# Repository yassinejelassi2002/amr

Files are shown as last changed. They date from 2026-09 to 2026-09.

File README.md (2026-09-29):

# AMR-X

AMR-X is an Autonomous Modular Robot - Extended project for a modular mobile robot platform and interchangeable functional modules.

To see the common commands for the website, MkDocs, dashboard, robot,
Gazebo worlds, navigation, and reports, run:

```bash
npm run commands
```

Filter the guide by category with commands such as `npm run commands -- robot`
or `npm run commands -- worlds`. `make help` shows the complete guide too.

This repository is structured for internship team work through GitHub issues, controlled CSV tables, LaTeX reports, and pull request review.

## Final Reports

- `reports/market_study/` - Final Market Study Report in LaTeX.
- `reports/v1_product_definition/` - Final V1 Product Definition Dossier in LaTeX.
- `reports/system_requirements_v1/` - Submitted SRD documents migrated as a standalone LaTeX report.

## Robotics Environment

The default robotics environment for this repository is:

- `Ubuntu 24.04`
- `ROS 2 Jazzy`
- `Gazebo Harmonic`

`Ubuntu 22.04 + ROS 2 Humble + Gazebo Fortress` is still allowed as a
compatibility path for teams that need to continue on the older setup.

Both teams must report any crash, launch failure, bridge mismatch, dependency
issue, or environment-specific problem immediately so the code and
documentation can be corrected quickly.

The default stack is the only acceptance target for new robotics work. The
older stack is a compatibility path, not a second implementation track.

Generated PDFs belong under `build/<report_name>/` and are not committed.

## Robotics Quick Start

The supported robotics stack is Ubuntu 24.04, ROS 2 Jazzy, and Gazebo
Harmonic. Build from the repository root:

```bash
source /opt/ros/jazzy/setup.bash
rosdep install --from-paths robotics --ignore-src -r -y
colcon build --symlink-install
source install/setup.bash
```

Launch the default warehouse simulation:

```bash
ros2 launch bringup simulation.launch.py
```

Launch the hospital instead:

```bash
ros2 launch bringup simulation.launch.py environment:=hospital
```

For SLAM, use separate sourced terminals:

```bash
# Terminal 1
ros2 launch bringup simulation.launch.py rviz:=false

# Terminal 2
ros2 launch navigation slam.launch.py

# Terminal 3
ros2 run teleop_twist_keyboard teleop_twist_keyboard
```

See the [complete robotics launch guide](robotics/LAUNCHING.md) for all worlds,
RViz, teleoperation, SLAM, map saving, live navigation, saved-map localization,
Fortress compatibility, topic checks, and troubleshooting.

## Source of Truth

- `config/project_specs.json` - Global project specifications.
- `data/bom/` - Controlled BOM source tables.
- `data/components/` - Component candidate source tables.
- `data/modules/` - Module decision and interface source tables.
- `data/requirements/` - Requirements matrix source tables.
- `reports/**/tables/generated/` - Generated LaTeX tables created from CSV and JSON sources.

Do not manually duplicate payload, dimensions, speed, endurance, or interface values in report prose. Use the global specs and generated tables.

## Module Scope

- `modules/base_platform/` - Base robot platform.
- `modules/arm_module/` - Robotic arm module.
- `modules/shelf_access_module/` - Shelf-access module.
- `modules/secure_compartment_module/` - Secure delivery compartment module.
- `modules/sensor_inspection_module/` - Sensor and inspection module.
- `modules/common_interface/` - Shared module mechanical, electrical, data, and safety interface.

Every major base component and every module must document a build, buy, modify, or custom-manufacture decision.

## Workflow

Issue -> Branch -> CSV/TEX edit -> Generate tables -> Pull request -> Review -> Merge

Run generators after changing `config/` or `data/`:

```bash
python3 tools/generate_specs.py
python3 tools/generate_latex_tables.py
```

Build reports into `build/<report_name>/`:

```bash
bash tools/build_reports.sh
```

Expected generated PDFs:

- `build/market_study/market_study.pdf`
- `build/v1_product_definition/v1_product_definition.pdf`
- `build/system_requirements_v1/system_requirements_v1.pdf`

## Local Website and Documentation

The documentation can run by itself. The Next.js landing page is optional.
The supported minimum versions are Python 3.10, Node.js 20.9, and npm 10.
Ubuntu is the primary local development environment.

### Documentation only (no website packages)

This path creates the shared root `.venv` and installs only the Python
documentation dependencies. The versions are pinned in
`requirements-docs.txt`, including the multilingual `mkdocs-static-i18n`
plugin:

```bash
git clone git@github.com:cybermech-hub/amr-x.git
cd amr-x
npm run setup:docs
npm run docs
```

Open <http://127.0.0.1:8001/>. You do not need to install anything under
`website/`. The setup script creates or reuses the single root `.venv`; do not
create another environment for documentation or the dashboard.

Always use `npm run docs` or `.venv/bin/python -m mkdocs`; a globally installed
`mkdocs` command does not use the repository's plugins. The supported command
checks the pinned toolchain and repairs missing documentation dependencies
before starting.

### Website and documentation together

```bash
git clone git@github.com:cybermech-hub/amr-x.git
cd amr-x
npm run setup
npm run dev
```

- Website: <http://localhost:3000/>
- Documentation: <http://localhost:3000/docs/>

French, German, and Arabic are available from the language selector:

| Language | Website | Documentation |
|---|---|---|
| English | <http://localhost:3000/> | <http://localhost:3000/docs/> |
| Français | <http://localhost:3000/fr/> | <http://localhost:3000/docs/fr/> |
| Deutsch | <http://localhost:3000/de/> | <http://localhost:3000/docs/de/> |
| العربية | <http://localhost:3000/ar/> | <http://localhost:3000/docs/ar/> |

English is the canonical documentation source. Localized Markdown files use
the `.fr.md`, `.de.md`, and `.ar.md` suffixes, with English fallback for pages
that have not yet been translated.

### How documentation translation works

Translation happens from Markdown source during the MkDocs build. It is not
performed dynamically in the browser, and the site does not call a runtime
translation service.

Current coverage:

- Documentation navigation and the homepage are translated into French,
  German, and Arabic.
- Technical pages currently use the English fallback until a translated
  Markdown file is added.
- Next.js landing-page translations are maintained separately in
  `website/lib/i18n.js`.

Translation files are stored beside the canonical English source:

```text
docs/robotics/simulation.md       # English
docs/robotics/simulation.fr.md    # French
docs/robotics/simulation.de.md    # German
docs/robotics/simulation.ar.md    # Arabic
```

They generate these routes:

```text
/docs/robotics/simulation/
/docs/fr/robotics/simulation/
/docs/de/robotics/simulation/
/docs/ar/robotics/simulation/
```

Do not translate commands, code, filenames, ROS identifiers, API paths, or
configuration keys. Preserve the technical structure and update translations
when the English source changes. See the
[documentation localization guide](docs/reference/localization.md) for the
complete workflow and current coverage.

`npm run setup` is safe to repeat. It prepares `.venv`, installs the MkDocs
dependencies, and installs the website packages. Press `Ctrl+C` once to stop
both development servers; run `npm run dev` to restart them. The optional
website alone can be prepared with `npm run setup:website` and started with
`npm run website`.

Edit the landing page under `website/app/`. Edit documentation Markdown under
`docs/`, and control its navigation in `mkdocs.yml`. MkDocs watches those files
and automatically refreshes open documentation pages. To add a page, create a
Markdown file under `docs/`, add it to `nav` in `mkdocs.yml`, and follow the
[documentation contributor guide](docs/contributing.md).

Before opening a pull request for the landing page or documentation, run
`npm run check`, or `npm run check:docs` when changing documentation only.
For dashboard changes, run `npm run check:dashboard`. Generated `site/`,
`website/.next/`, and dashboard `dist/` output must not be committed.

If a server reports that its port is busy, stop the process using port 3000,
3001, or 8001 and retry. In combined mode, the local gateway owns port 3000,
Next.js runs internally on port 3001, and MkDocs runs internally on port 8001.
If a command reports missing dependencies, run the matching setup command
again. If virtual-environment creation is unavailable on Ubuntu, install the
OS package that provides `python3-venv` for your Python version.

No public deployment, hosting provider, or GitHub Pages workflow is configured.

## Dashboard Development

The operator dashboard consists of a React/Vite frontend, a FastAPI backend,
and PostgreSQL 16 in Docker. It uses the same repository-root `.venv` as the
documentation toolchain; do not create a virtual environment under
`dashboard_app/`.

First-time setup:

```bash
npm run setup:dashboard
```

Start the complete dashboard:

```bash
npm run dashboard
```

This starts PostgreSQL, FastAPI, and Vite:

- Dashboard: <http://localhost:5173/>
- API documentation: <http://localhost:8000/docs>

Press `Ctrl+C` to stop the frontend and backend. PostgreSQL remains running so
its data is available next time. Stop it separately with
`npm run dashboard:db:stop`.

Individual services can also be run from the repository root:

```bash
npm run dashboard:db          # Start PostgreSQL
npm run dashboard:backend     # Start FastAPI on port 8000
npm run dashboard:frontend    # Start Vite on port 5173
npm run dashboard:db:status   # Show PostgreSQL status
npm run dashboard:db:logs     # Follow PostgreSQL logs
npm run dashboard:db:stop     # Stop PostgreSQL without deleting its data
npm run check:dashboard       # Check the backend and lint/build the frontend
```

See the [dashboard guide](dashboard_app/README.md), the
[backend guide](dashboard_app/backend/README.md), and the
[full ROS-to-dashboard setup](dashboard_app/SETUP.md) for more detail.

## Rules

- Start every task from a GitHub issue.
- Use `TBD` for undecided values.
- Do not invent market data, prices, suppliers, specifications, or citations.
- Do not commit private PDFs.
- Do not commit generated LaTeX build files or report PDFs.
- Keep source PDFs and references only when they are allowed to be shared.

See `CONTRIBUTING.md`, `.agents.md`, and the
[documentation contributor guide](docs/contributing.md).

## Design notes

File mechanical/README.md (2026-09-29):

# Mechanical

Mechanical design, CAD exports, and hardware specifications.

## Purpose

Define and document robot chassis, mounting interfaces, payload support, and mechanical architecture.

## CAD Tool

TBD - Tool selection pending.

## Git Storage Policy

Active CAD files (proprietary formats) are not stored in Git at the beginning. Store only:

- Exported STEP files
- Exported STL files
- PDF drawings and technical documentation
- Rendered images and concept visualizations
- Design concept notes

## Future Work

- Chassis design and optimization
- Modular add-on mounting standard
- Payload capacity and assumptions
- Serviceability and maintenance notes
- Material and manufacturing process specifications

## Subfolders

- `concepts/` - Design concepts and sketches
- `dimensions/` - Mechanical specifications and constraints
- `mounting_interface/` - Modular add-on interface design
- `exports/` - STEP, STL, drawings, and renders

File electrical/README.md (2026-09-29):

# Electrical

Electrical systems, power distribution, sensors, compute, and bill of materials.

## Purpose

Design and document electrical architecture for autonomous mobile robot platform.

## Electrical CAD Tool

TBD - Tool selection pending.

## Current Status

No component selection finalized yet. Design phase only.

## Architecture Areas

- **Power Distribution** - Voltage regulation, protection, distribution
- **Battery System** - Energy storage and management
- **Sensors** - Power requirements and interfaces
- **Compute** - Processing platform and controllers
- **Wiring** - Harness design and connections
- **Safety Systems** - Emergency stop, protection, monitoring
- **BOM** - Component tracking and specifications

## Security and Safety Notes

- Emergency stop must be designed with safety-critical approach
- Power protection circuits required for component safety
- No remote control without authentication (enforced at software level)
- All operator actions logged for audit trail

## Subfolders

- `power_system/` - Power distribution design
- `battery/` - Battery system specifications
- `sensors/` - Sensor selection and power requirements
- `compute/` - Compute platform details
- `wiring/` - Harness and connection design
- `safety/` - Safety systems and interlocks
- `bom/` - Bill of materials

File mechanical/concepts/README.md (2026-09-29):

# Concepts

Early design concepts and sketches for robot platform.

## Purpose

Document and iterate on mechanical design concepts before finalizing CAD models.

Store concept notes, sketches, and design rationale.

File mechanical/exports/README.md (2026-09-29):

# Exports

CAD file exports including STEP, STL, drawings, and renders.

## Purpose

Store exported CAD data suitable for manufacturing, simulation, and documentation.

## Subfolders

- `step/` - STEP format files for CAD interchange
- `stl/` - STL format files for 3D printing and simulation
- `drawings/` - PDF technical drawings
- `renders/` - Visualization renders and concept images

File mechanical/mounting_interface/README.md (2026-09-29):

# Mounting Interface

Modular add-on mounting interface and integration standard.

## Purpose

Define the mechanical, electrical, and software interface for modular add-ons and extensions.

Store mounting specifications, interface standards, and integration guidelines.

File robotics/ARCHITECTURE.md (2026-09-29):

# AMR-X Modular Architecture

Scaffold for expanding AMR-X from a mobile base into a modular mobile
manipulator. First module is a dual arm; the framework is general.

Status: skeleton that builds. Robot logic is TODO(team) stubs.

## Documentation map
- README.md       - base robot workspace (build/run the base)
- LAUNCHING.md    - run commands (sim, teleop, SLAM, Nav2)
- ARCHITECTURE.md - this file: the modular expansion (arm + modules)

## Packages

| Package | Build type | Role |
|---|---|---|
| amr_interfaces | ament_cmake | Shared msg/srv/action. BUILD FIRST. |
| arm_description | ament_cmake | Dual-arm module URDF/Xacro. |
| arm_control | ament_cmake | ros2_control controllers for arm joints. |
| arm_moveit_config | ament_cmake | MoveIt 2 planning (Setup Assistant output). |
| module_manager | ament_python | Runtime attach/detach + mode transitions. |
| task_coordinator | ament_python | Mission orchestration (mobile manipulation). |
| dashboard_bridge | ament_python | ROS 2 <-> dashboard telemetry/commands. |

Alongside existing base packages: robot_description, simulation, control,
navigation, bringup.

## Build

    cd ~/amr-x/robotics
    rosdep install --from-paths . --ignore-src -r -y
    colcon build --packages-select amr_interfaces
    source install/setup.bash
    colcon build
    source install/setup.bash

Human build order: amr_interfaces -> arm_description -> arm_control ->
arm_moveit_config -> module_manager / task_coordinator -> dashboard_bridge.

## Where to start (per package)

- amr_interfaces: refine and FREEZE the msg/srv/action definitions early.
- arm_description: fill config/arm_params.yaml, then single_arm.xacro (L+R),
  gripper.xacro, arm_gazebo.xacro. Goal: view the arm in RViz.
- arm_control: joint_trajectory_controller per arm + joint_state_broadcaster.
- arm_moveit_config: run MoveIt Setup Assistant on the arm URDF; commit output.
- module_manager: attach/detach (spawn controllers) + mode state machine.
- task_coordinator: pick-and-place behavior tree (navigate->grasp->place).
- dashboard_bridge: telemetry out / commands in, typed via amr_interfaces.

## Suggested ownership

- Interfaces + architecture: amr_interfaces, mount-frame convention.
- Description/sim: arm_description, simulation extensions.
- Control/motion: arm_control, arm_moveit_config.
- Coordination: module_manager, task_coordinator.
- Dashboard: dashboard_bridge, dashboard_app.

## Module mount interface (pending mechanical)

Guided by modules/common_interface/ (connector selection guides, not final spec).
- Base exposes one frame: module_mount_top; modules attach there.
- Per-module details in module_manager/config/modules.yaml.
- DUAL ARM: bolted-flange / kinematic mount (heavy, calibration-sensitive) ->
  NOT runtime hot-swappable; present at launch. Electrical: CAN + M8/M12.
- TODO(mechanical): confirm connector + which modules are hot-swappable.

## Simulator stack - MIXED (Fortress + Harmonic coexist)

Some members: ROS 2 Humble + Gazebo Fortress. Others: Jazzy + Harmonic. To cope:

| Thing | FORTRESS | Harmonic |
|---|---|---|
| DiffDrive plugin file | libignition-gazebo-diff-drive-system.so | gz-sim-diff-drive-system |
| Plugin namespace | ignition::gazebo::systems:: | gz::sim::systems:: |
| Sensor frame tag | <ignition_frame_id> | <gz_frame_id> |
| Bridge msg prefix | ignition.msgs.X | gz.msgs.X |
| Resource env var | IGN_GAZEBO_RESOURCE_PATH | GZ_SIM_RESOURCE_PATH |
| apt packages | ros-humble-* | ros-jazzy-* |

- Keep ALL simulator-specific strings in ONE file per package (*_gazebo.xacro,
  bridge YAML). State the target stack in each world/launch header.
- Prefer parameterizing plugin names via a xacro arg so one file targets either.
- Check a machine: echo $ROS_DISTRO (humble=Fortress, jazzy=Harmonic).

## Conventions

- Each package's params in a single config/*.yaml.
- Isolate simulator-specific tags in one xacro per package.
- build/ install/ log/ are git-ignored; never commit them.

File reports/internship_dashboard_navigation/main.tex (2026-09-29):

% Rapport de stage - Interface web de supervision et de commande AMR-X
% Compilation : latexmk -pdf -outdir=../../build/internship_dashboard_navigation main.tex
\documentclass[12pt,a4paper,oneside]{report}

\usepackage[utf8]{inputenc}
\usepackage[T1]{fontenc}
\usepackage{lmodern}
\usepackage[french]{babel}
\usepackage[a4paper,top=2.5cm,bottom=2.5cm,left=2.5cm,right=2.5cm,headheight=15pt]{geometry}
\usepackage{amsmath,amssymb}
\usepackage{graphicx}
\usepackage{booktabs,tabularx,multirow,longtable,array}
\usepackage[table]{xcolor}
\usepackage{caption,subcaption}
\usepackage{fancyhdr}
\usepackage{titlesec}
\usepackage{tocloft}
\usepackage{enumitem}
\usepackage{listings}
\usepackage{tikz}
\usetikzlibrary{arrows.meta,positioning,shapes.geometric,fit,calc,babel}
\usepackage{setspace}
\usepackage[hidelinks]{hyperref}

\setstretch{1.2}
\setlength{\parindent}{1.5em}
\setlength{\parskip}{0.4em}
\graphicspath{{figures/}}

% ---------------------------------------------------------------- numérotation
\renewcommand{\thechapter}{\Roman{chapter}}
\renewcommand{\thesection}{\arabic{section}}
\renewcommand{\thesubsection}{\arabic{section}.\arabic{subsection}}
\renewcommand{\thefigure}{\thechapter.\arabic{figure}}
\renewcommand{\thetable}{\thechapter.\arabic{table}}
\setcounter{secnumdepth}{3}
\setcounter{tocdepth}{2}

% ---------------------------------------------------------------- titres
\titleformat{\chapter}[display]
  {\normalfont\huge}{\chaptertitlename\ \thechapter}{1.2cm}{\Huge}
\titlespacing*{\chapter}{0pt}{2cm}{1.2cm}
\titleformat{\section}{\normalfont\Large\bfseries}{\thesection}{1em}{}
\titleformat{\subsection}{\normalfont\large\bfseries}{\thesubsection}{1em}{}
\captionsetup{labelsep=endash,font=small}
\captionsetup[figure]{name={\textsc{Figure}}}
\captionsetup[table]{name={\textsc{Tableau}}}

% ---------------------------------------------------------------- en-têtes
\pagestyle{fancy}
\fancyhf{}
\fancyhead[L]{\small\itshape\leftmark}
\fancyfoot[R]{\thepage}
\renewcommand{\headrulewidth}{0.4pt}
\renewcommand{\footrulewidth}{0.4pt}
\renewcommand{\chaptermark}[1]{\markboth{\chaptertitlename~\thechapter.\ #1}{}}
\fancypagestyle{plain}{\fancyhf{}\fancyfoot[C]{\thepage}%
  \renewcommand{\headrulewidth}{0pt}\renewcommand{\footrulewidth}{0pt}}

\renewcommand{\cfttoctitlefont}{\normalfont\Huge}
\renewcommand{\cftloftitlefont}{\normalfont\Huge}
\renewcommand{\cftlottitlefont}{\normalfont\Huge}
\renewcommand{\cftmarktoc}{\markboth{Table des matières}{}}
\renewcommand{\cftmarklof}{\markboth{Table des figures}{}}
\renewcommand{\cftmarklot}{\markboth{Liste des tableaux}{}}
\setlength{\emergencystretch}{3em}
\renewcommand{\topfraction}{0.9}
\renewcommand{\textfraction}{0.1}
\renewcommand{\floatpagefraction}{0.8}
\renewcommand{\cftdotsep}{1.5}
\renewcommand{\cftchapleader}{\hfill}

% ---------------------------------------------------------------- listings
\lstset{basicstyle=\ttfamily\small,columns=fullflexible,breaklines=true,
  frame=single,framerule=0.3pt,rulecolor=\color{gray!60},
  backgroundcolor=\color{gray!6},xleftmargin=0.5em,xrightmargin=0.5em,
  showstringspaces=false,upquote=true}

% ---------------------------------------------------------------- macros
% Valeur à compléter par l'auteur (organisme, encadrants, dates).
\newcommand{\acompleter}[1]{\textcolor{red!70!black}{[#1]}}
% Capture d'écran : insérée si le fichier existe dans figures/, sinon cadre réservé.
\newcommand{\capture}[3][0.9\linewidth]{%
  \IfFileExists{figures/#2}{}{%
    \fbox{\parbox[c][5.5cm][c]{#1}{\centering\small\itshape
      Capture à insérer : figures/#2\\[0.5em]\upshape #3}}}}
\newcommand{\code}[1]{\texttt{#1}}

% Style commun des schémas TikZ
\tikzset{
  bloc/.style={draw,rounded corners=3pt,thick,align=center,minimum height=1cm,
    inner sep=5pt,font=\small},
  web/.style={bloc,fill=blue!8},
  ros/.style={bloc,fill=orange!12},
  sim/.style={bloc,fill=green!10},
  neuf/.style={bloc,fill=red!8,draw=red!60!black,very thick},
  fl/.style={-{Stealth[length=2.5mm]},thick},
  lbl/.style={font=\scriptsize,align=center,fill=white,inner sep=1.5pt},
}

\begin{document}

\input{chapters/00_front}

\pagenumbering{roman}
\input{chapters/01_preliminaires}

\cleardoublepage
\pagenumbering{arabic}
\input{chapters/02_introduction}
\input{chapters/03_contexte}
\input{chapters/04_conception}
\input{chapters/05_realisation}
\input{chapters/06_validation}
\input{chapters/07_conclusion}

\end{document}

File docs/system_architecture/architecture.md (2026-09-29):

# AMR-X System Architecture v0.2

| Document control | Value |
|---|---|
| Owner | Technical Project Manager / System Architect |
| Status | Draft |
| Revision | `v0.2` |
| Controlled interface data | `data/system_architecture/interfaces.csv` |

!!! warning "Draft architecture"
    Proposed values and open conflicts are not approved requirements. Treat
    only entries explicitly marked **Confirmed** in the controlled interface
    data as confirmed decisions.

This document is the single reference for how the mechanical, electrical,
software, and module-interface decisions fit together. It should be updated
as teams confirm or change values. Detailed values live in
`data/system_architecture/interfaces.csv` — do not duplicate numbers here,
reference the table.

**Related implementation document:** `robotics/ARCHITECTURE.md`
covers the ROS 2 package-level implementation of the module software stack
in detail. This document stays at the system level and links out to it
rather than duplicating package contents — see Section 4.

## 1. Overview

AMR-X is a modular autonomous mobile robot. One base robot chassis accepts
interchangeable functional modules (inspection, secure cargo, handling,
robotic arm) through a shared docking interface. The base handles movement,
navigation, and power; the module handles the task-specific function. The
dual-arm module has been confirmed as the first module to be built (V1).

### Responsibility boundaries

| System element | Primary responsibility |
|---|---|
| Mobile base | Movement, navigation, base power, and module support |
| Functional module | Task-specific mechanical and software capability |
| Shared docking interface | Mechanical alignment and retention, power, data, and safety boundaries |
| Module manager | Module identification and software lifecycle coordination |

## 2. Mechanical Architecture

- Overall footprint: 800 mm x 600 mm x 420 mm (confirmed by Mechanical team)
- Drive: differential drive
- Wheels: 4 caster wheels (changed from 2 for stability and load
  distribution, relevant now that a heavier dual-arm module is planned)
- Module mounting zone: 500 mm x 400 mm, centered over the wheelbase
- A real CAD-exported URDF has been produced and integrated into
  simulation (see Section 4). Driving behavior and LiDAR output from the
  real model are still being validated.
- The dual-arm module is expected to require a center-of-gravity
  compensation of roughly 30-50 mm toward the rear (proposed, not yet
  validated in CAD)

Open item: internal component layout (battery, controller, wiring) is
still waiting on the Electrical team's final part list.

<div class="visual-grid">
  <figure>
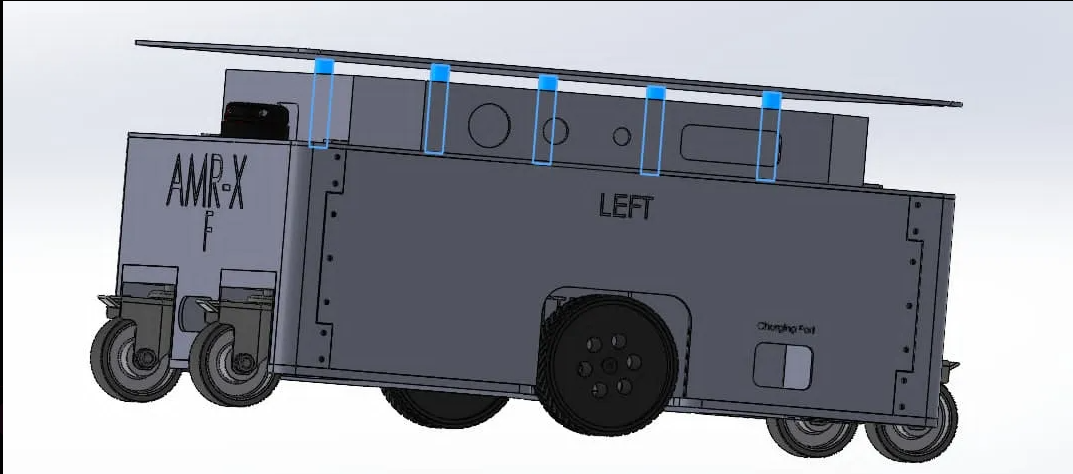
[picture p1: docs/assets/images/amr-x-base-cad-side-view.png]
Current AMR-X mobile base CAD side-view capture
    
    <figcaption><strong>Current base CAD capture.</strong><span>Progress image only; controlled dimensions remain in project data.</span></figcaption>
  </figure>
  <figure>
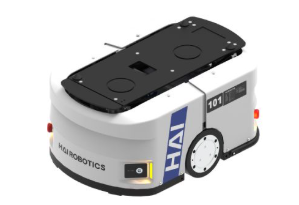
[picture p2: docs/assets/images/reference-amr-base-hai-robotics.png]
Third-party AMR base used as a form-factor reference
    
    <figcaption><strong>Base form-factor reference.</strong><span>External reference placeholder, not AMR-X.</span></figcaption>
  </figure>
  <figure>
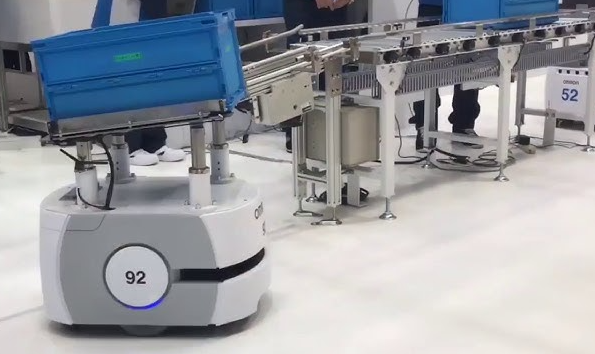
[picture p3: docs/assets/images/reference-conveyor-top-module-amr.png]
Third-party AMR with a conveyor top module
    
    <figcaption><strong>Top-module reference.</strong><span>External material-transfer example, not AMR-X.</span></figcaption>
  </figure>
</div>

## 3. Electronics Architecture

- Battery: TBD, active research in progress
- Main computer / controller: TBD
- Motor drivers: TBD

Open item: none of these are selected yet. This remains the biggest
blocker for Mechanical's internal layout.

## 4. Software Architecture

- ROS 2 stack locked: **Ubuntu 24.04 + ROS 2 Jazzy + Gazebo Harmonic** as
  the default, with **Ubuntu 22.04 + ROS 2 Humble + Gazebo Fortress** kept
  as a supported compatibility path
- Full simulation loop is working end-to-end: the robot drives in a
  warehouse world with working teleoperation and LiDAR/IMU/odometry
  publishing correctly
- The real CAD-exported URDF is integrated and spawns correctly in Gazebo,
  replacing the earlier placeholder model. Still to confirm: driving
  behavior and `/scan` output from the real sensor configuration
- **Module software scaffold merged into main (PR #8):** 7 ROS 2 packages
  — `amr_interfaces`, `arm_description`, `arm_control`, `arm_moveit_config`,
  `module_manager`, `task_coordinator`, `dashboard_bridge`. This is an
  empty-but-buildable skeleton with real logic left as TODOs per package
  owner. Full detail in `robotics/ARCHITECTURE.md`. **Merged on 8 Jul
  without the frame-naming conflict below being resolved first.**
- Arm control will use **MoveIt2**, not Nav2, since the dual-arm module's
  job is manipulation rather than mobile navigation
- Dashboard communicates with ROS 2 over `rosbridge_server` and
  `roslibjs` via WebSocket; confirmed working for `/cmd_vel`, with
  `/odom` and `/imu` subscriptions planned next

<div class="visual-grid visual-grid--two">
  <figure>
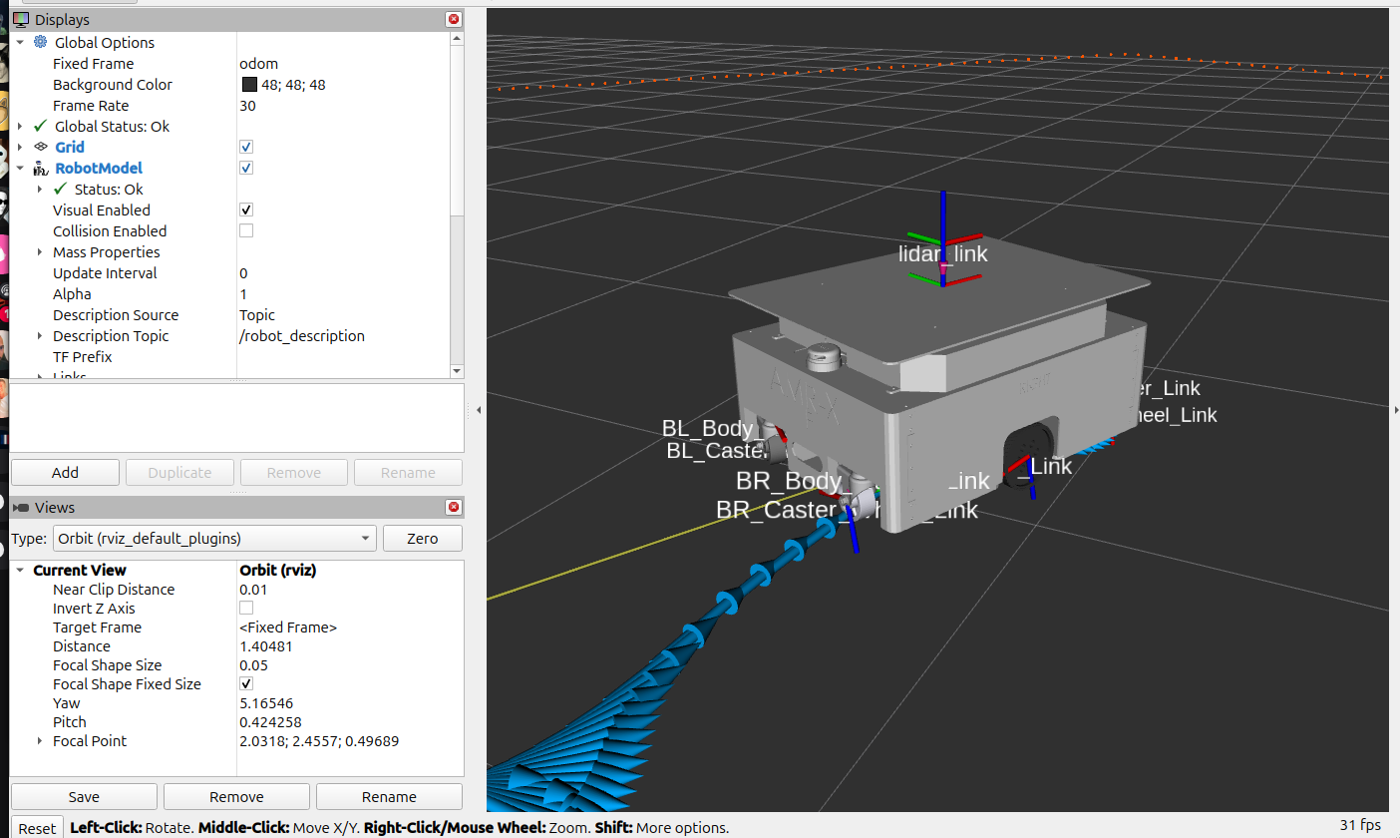
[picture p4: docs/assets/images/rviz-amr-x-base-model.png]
AMR-X base model and frames in RViz
    
    <figcaption><strong>AMR-X base in RViz.</strong><span>Robot-model integration capture.</span></figcaption>
  </figure>
  <figure>
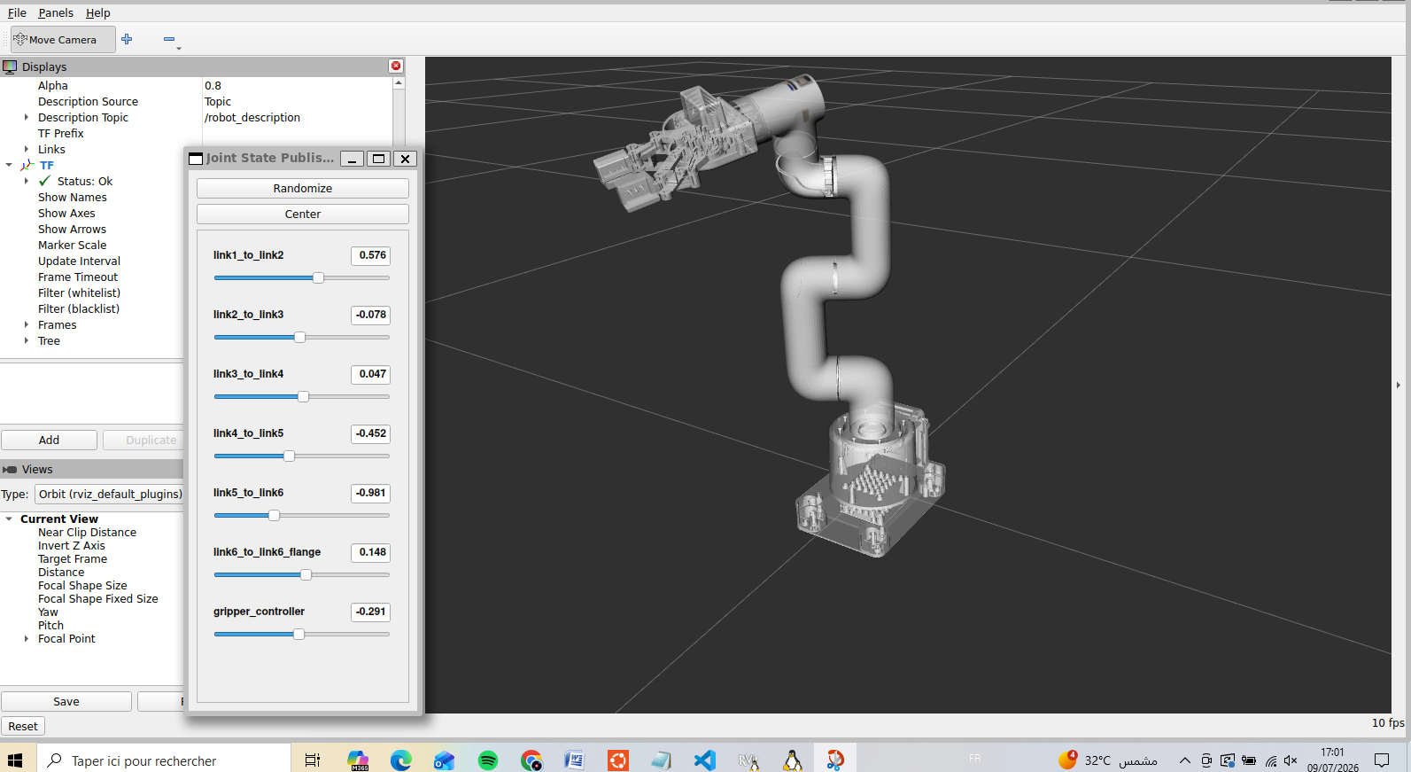
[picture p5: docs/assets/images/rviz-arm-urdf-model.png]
Arm URDF and joint states in RViz
    
    <figcaption><strong>Arm URDF in RViz.</strong><span>Manipulation-model integration capture.</span></figcaption>
  </figure>
  <figure>
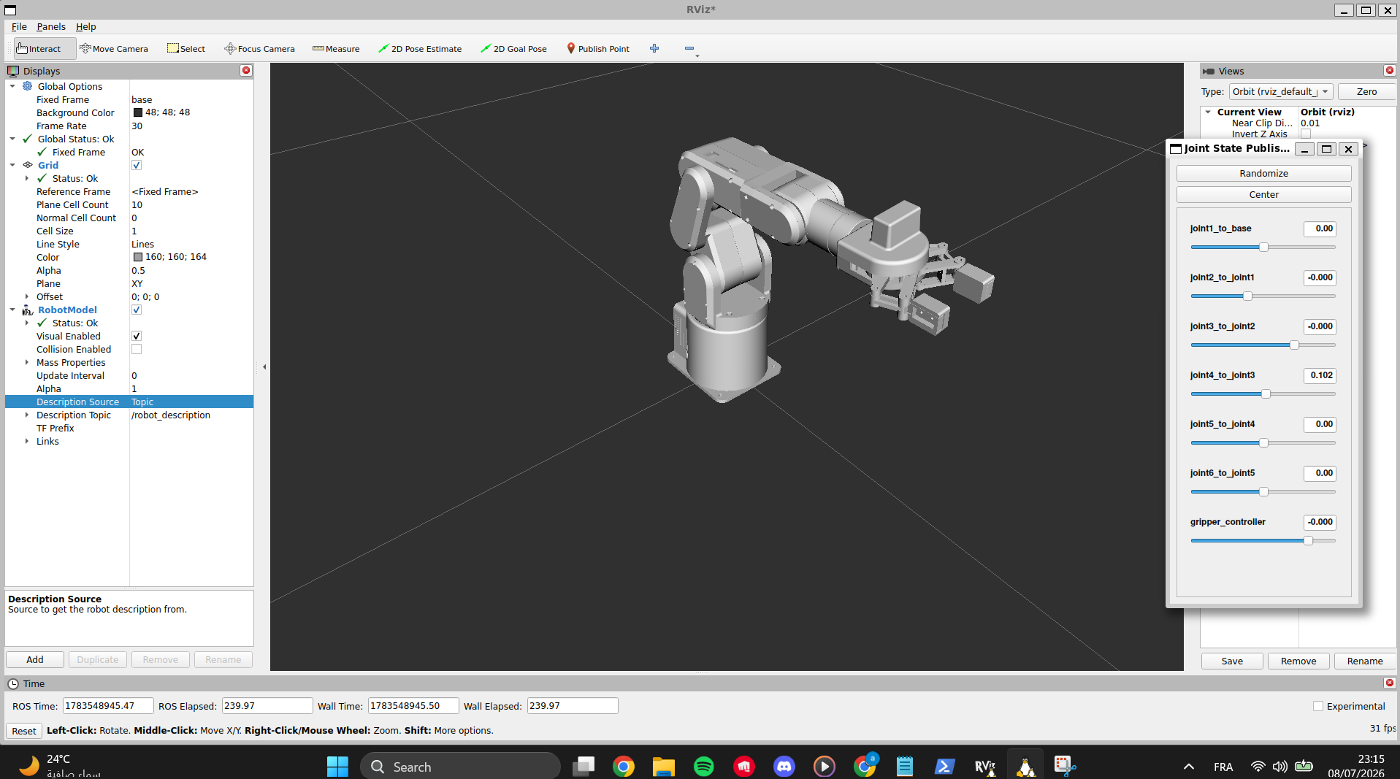
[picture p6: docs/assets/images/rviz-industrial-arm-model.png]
Alternative industrial arm model displayed in RViz
    
    <figcaption><strong>Alternative arm in RViz.</strong><span>Model visualization capture.</span></figcaption>
  </figure>
  <figure>
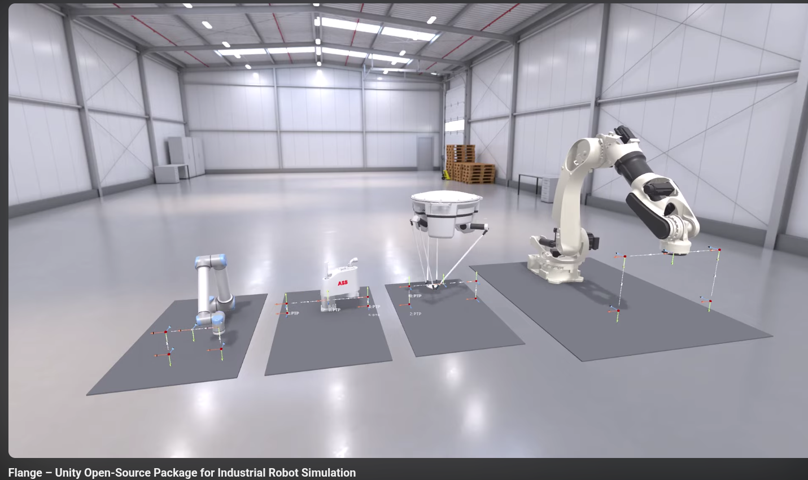
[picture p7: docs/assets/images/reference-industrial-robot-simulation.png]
Industrial robot simulation environment reference
    
    <figcaption><strong>Simulation presentation reference.</strong><span>External reference placeholder, not the AMR-X simulator.</span></figcaption>
  </figure>
</div>

## 5. Module Interface

- Connector: HARTING Han-Modular, carrying 24V power, CAN bus, and
  Ethernet
- Docking alignment: 12 mm diameter guide pins on a 450 x 350 mm pattern
- Docking locks: quarter-turn M8 locks, rated to 375 kg
- Docking detection: 2 inductive sensors, published to ROS topics
  `/module_docked` and `/module_id`
- Clearance zones defined so future modules cannot block the front LiDAR,
  emergency stop, or operator panel
- **Open conflict — module mount frame naming:** the mechanical/URDF side
  refers to the mount point as `module_interface_link`, while the new ROS
  package scaffold from PR #8 defines it as `module_mount_top`. These need
  to be reconciled to a single canonical name before more packages are
  built assuming either one. See Section 9.

## 6. Sensor Layout

- Proposed: dual LiDAR (front + rear) for 360-degree coverage and
  redundancy, proposed by Mechanical
- The currently integrated test URDF places a single LiDAR link at the
  front-top-centre position, matching CAD — this does not yet confirm
  whether the dual-LiDAR plan is still active or has been narrowed to one
- **Still not confirmed by Navigation/ROS team** — flagged as an open
  conflict, see Section 9

## 7. Navigation

- Nav2 configured, but currently using a placeholder footprint
- SLAM and AMCL localization tested successfully against the placeholder
  robot model; an EKF sensor-fusion config is currently being drafted
- Now that a real URDF is integrated, the footprint may be finalizable
  soon once the caster layout is locked

<div class="visual-grid">
  <figure>
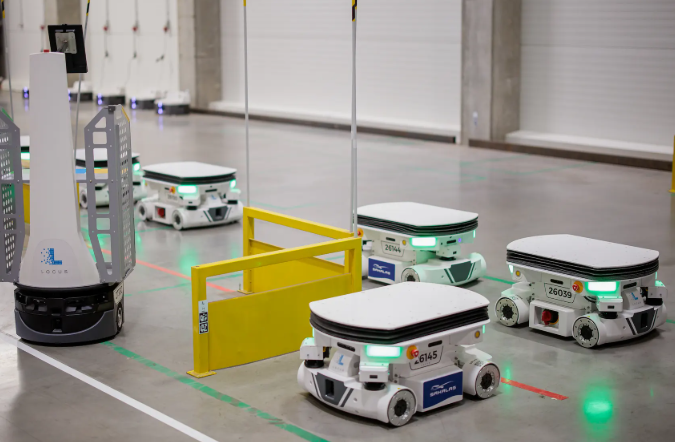
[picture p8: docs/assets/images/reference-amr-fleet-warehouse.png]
Fleet of third-party AMRs operating in a warehouse
    
    <figcaption><strong>Fleet-operation reference.</strong><span>External multi-robot environment placeholder.</span></figcaption>
  </figure>
  <figure>
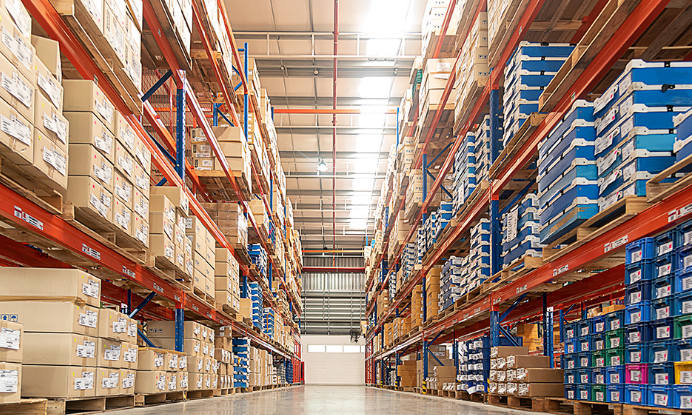
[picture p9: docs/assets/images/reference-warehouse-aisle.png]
Warehouse aisle used as an environment reference
    
    <figcaption><strong>Warehouse environment.</strong><span>Reference placeholder for navigation context.</span></figcaption>
  </figure>
  <figure>
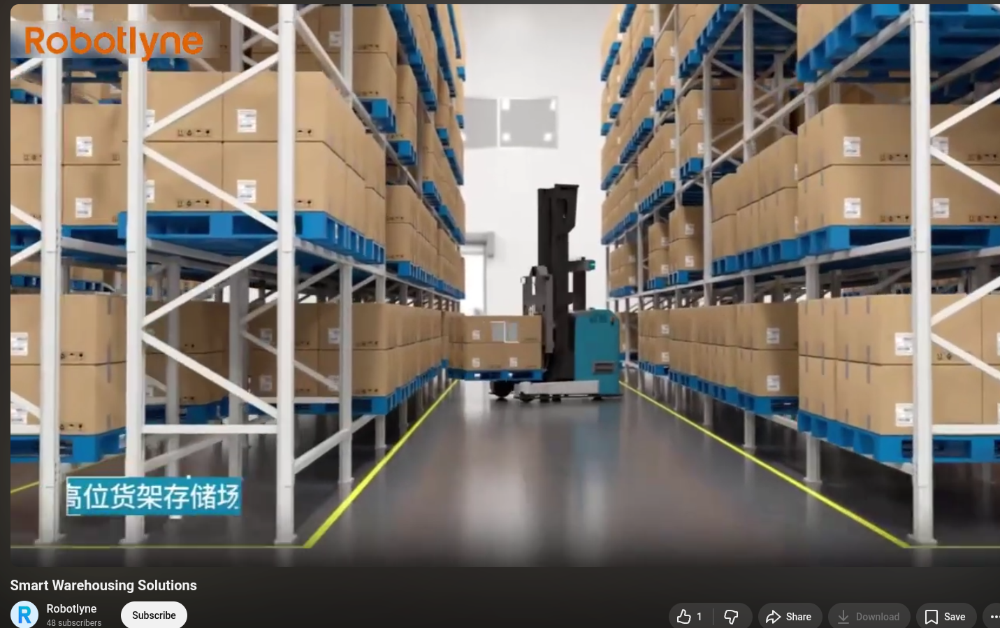
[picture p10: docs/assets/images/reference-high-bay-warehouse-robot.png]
Third-party robot operating in a high-bay warehouse
    
    <figcaption><strong>High-bay operation reference.</strong><span>External storage use-case placeholder.</span></figcaption>
  </figure>
</div>

## 8. Power Distribution

TBD — depends entirely on Electrical team's battery and controller
selection, which is under active research. No layout can be finalized
until this is resolved.

## 9. Known Conflicts / Open Questions

!!! danger "Integration blockers"
    This section identifies unresolved decisions that can invalidate work in
    more than one subsystem. Keep it synchronized with the controlled
    interface data.

1. **[NEW, urgent — now live in main]** Module mount frame naming
   conflict: `module_interface_link` (mechanical/URDF) vs
   `module_mount_top` (merged via PR #8). This is no longer a
   before-it-happens risk — PR #8 was merged into `main` on 8 Jul without
   this being reconciled, so the mismatch is now sitting in the codebase.
   Needs an issue opened and a decision between the Module team and
   ROS/Sim team on which name is canonical, then a follow-up fix wherever
   the losing name was used.
2. Mechanical proposes 2 LiDARs; the currently integrated URDF only shows
   one LiDAR link. Needs explicit confirmation from Navigation/ROS on
   whether the dual-LiDAR plan is still active.
3. Navigation's footprint is still a placeholder; likely close to
   resolution now that the real URDF is integrated, pending final caster
   layout confirmation.
4. Electrical has not selected a battery or controller yet, which blocks
   Mechanical's internal layout.
5. **[NEW]** Two parallel architecture documents now exist — this
   document (system-level) and `robotics/ARCHITECTURE.md` (ROS
   package-level, from PR #8). Agreed approach: this document stays at
   the system/interface level and links to `ARCHITECTURE.md` for
   implementation detail, rather than the two documents duplicating each
   other. Confirm this approach across the affected workstreams.

## 10. Future Modules

**Confirmed V1 module: dual-arm robotic arm module.** Mechanical is
researching hardware options (GrabCAD models); software has scaffolded
the arm packages (`arm_description`, `arm_control`, `arm_moveit_config`).

Candidate module research (from the module research source, see
`Modules.pdf`):

- **Robotic arm:** Interbotix PincherX/WidowX (ROS-ready "arm + mobile
  base" kits, ~$2,000-6,500), Elephant Robotics myCobot 280/320
  (lightweight, ~$1,000-2,000, lower payload), uFactory xArm/Lite
  (higher payload up to 5kg, ~$3,300-10,000)
- **Shelf access:** Nord Modules Quick Mover/Pallet Lift (4-screw
  mounting, up to 1500kg), ROEQ Top Modules (MiR-compatible, built-in
  alignment/load sensors), Ocado Chuck (design reference only, not
  purchasable)
- **Inspection:** Clearpath Husky Observer (turnkey, ROS API, 10kg
  payload budget), or individually-assembled components (e-con Systems
  cameras, Orbbec depth sensors, thermal imaging modules) — likely the
  more realistic budget option

Not yet scoped: shelf-access and inspection modules remain future work
beyond the dual-arm V1.

!!! info "Concept imagery"
    The images below are communication placeholders, not approved production
    geometry. Third-party references do not represent AMR-X work and require
    provenance and licensing review before external use.

### Dual-arm and mobile-manipulation direction

<div class="visual-grid">
  <figure>
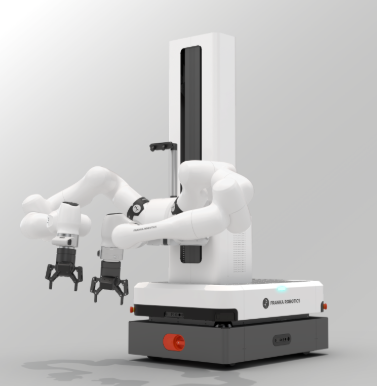
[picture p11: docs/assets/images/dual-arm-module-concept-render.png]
Dual-arm module concept placeholder
    
    <figcaption><strong>Dual-arm module direction.</strong><span>V1 concept placeholder.</span></figcaption>
  </figure>
  <figure>
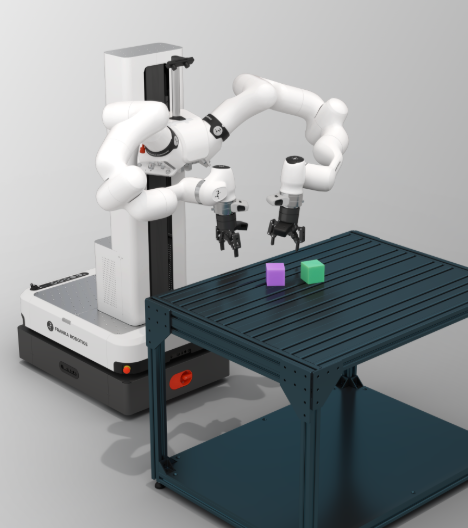
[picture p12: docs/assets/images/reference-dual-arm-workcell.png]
Third-party dual-arm workcell reference
    
    <figcaption><strong>Dual-arm workcell reference.</strong><span>External workspace placeholder, not AMR-X.</span></figcaption>
  </figure>
  <figure>
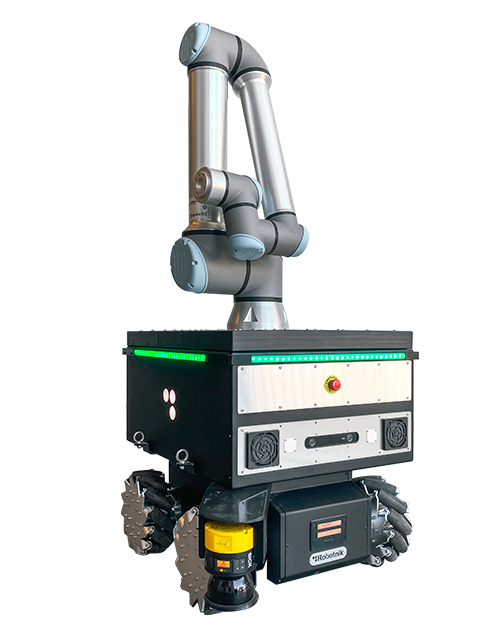
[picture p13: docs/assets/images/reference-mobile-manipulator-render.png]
Third-party mobile manipulator render
    
    <figcaption><strong>Manipulator packaging reference.</strong><span>External reference placeholder, not AMR-X.</span></figcaption>
  </figure>
  <figure>
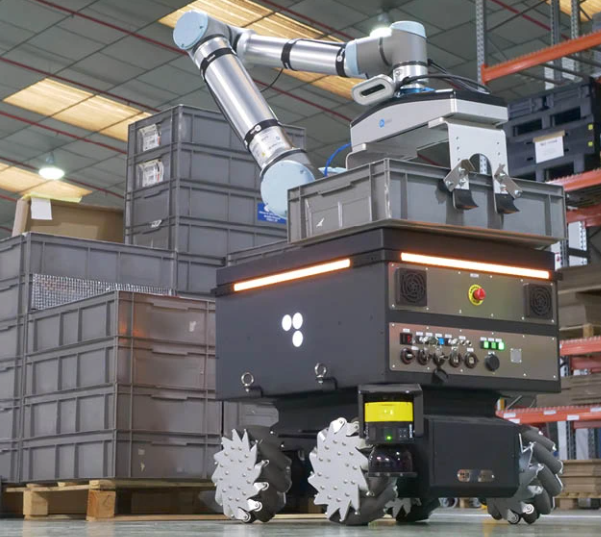
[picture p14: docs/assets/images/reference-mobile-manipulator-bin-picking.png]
Third-party mobile manipulator handling bins
    
    <figcaption><strong>Bin-handling reference.</strong><span>External use-case placeholder, not AMR-X.</span></figcaption>
  </figure>
  <figure>
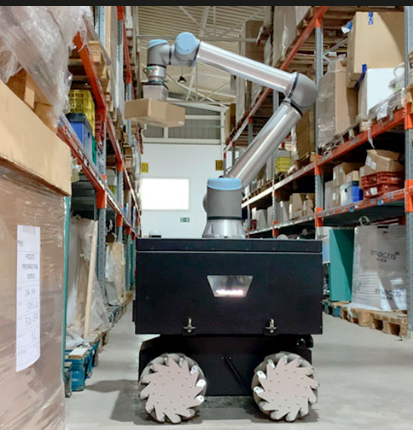
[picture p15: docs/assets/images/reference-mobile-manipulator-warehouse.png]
Third-party mobile manipulator in a warehouse aisle
    
    <figcaption><strong>Aisle-manipulation reference.</strong><span>External use-case placeholder, not AMR-X.</span></figcaption>
  </figure>
</div>

### Secure-compartment direction

<div class="visual-grid visual-grid--two">
  <figure>
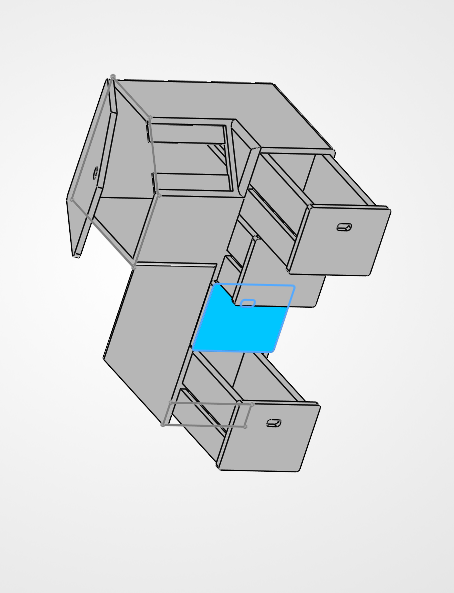
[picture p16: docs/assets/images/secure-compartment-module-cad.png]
Secure compartment module concept placeholder
    
    <figcaption><strong>Secure-compartment CAD.</strong><span>Future-module concept placeholder.</span></figcaption>
  </figure>
  <figure>
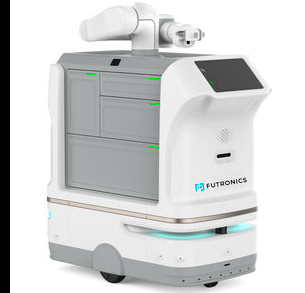
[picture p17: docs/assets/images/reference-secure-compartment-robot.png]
Third-party secure compartment robot reference
    
    <figcaption><strong>Compartment robot reference.</strong><span>External reference placeholder, not AMR-X.</span></figcaption>
  </figure>
</div>

### Shelf-access direction

<div class="visual-grid">
  <figure>
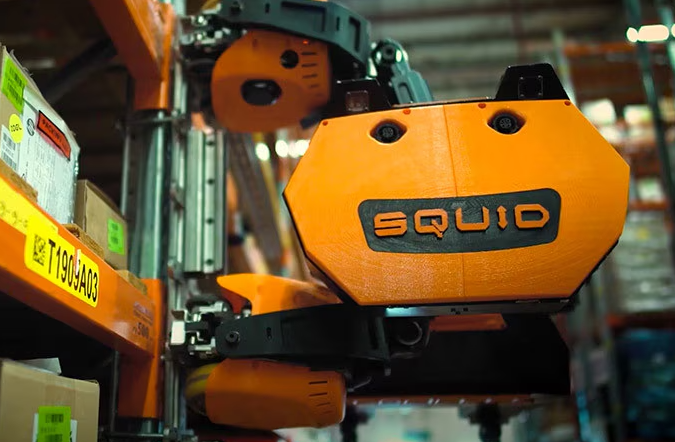
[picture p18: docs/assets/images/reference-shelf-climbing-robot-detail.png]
Detail of a third-party shelf-climbing robot
    
    <figcaption><strong>Rack-interface detail.</strong><span>External reference placeholder, not AMR-X.</span></figcaption>
  </figure>
  <figure>
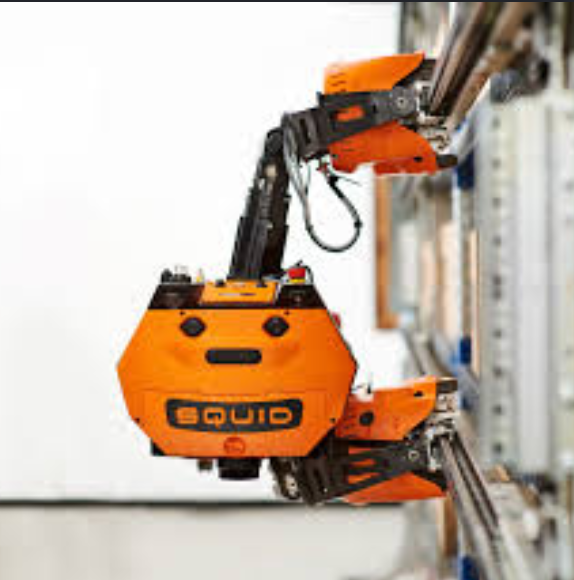
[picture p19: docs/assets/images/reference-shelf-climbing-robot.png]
Third-party shelf-climbing warehouse robot
    
    <figcaption><strong>Vertical-access reference.</strong><span>External reference placeholder, not AMR-X.</span></figcaption>
  </figure>
  <figure>
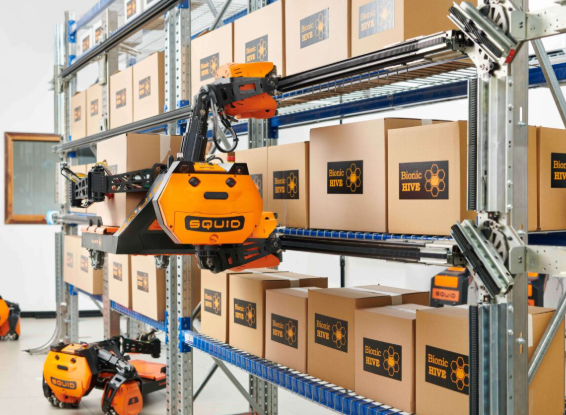
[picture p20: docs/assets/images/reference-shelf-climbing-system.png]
Third-party shelf-climbing robots operating on racks
    
    <figcaption><strong>Rack-automation system.</strong><span>External reference placeholder, not AMR-X.</span></figcaption>
  </figure>
</div>

---
*Change log*
- v0.1 — initial draft
- v0.2 — added dual-arm module confirmation, real URDF integration status,
  locked ROS stack decision, PR #8 module scaffold cross-reference, module
  mount frame naming conflict, precise docking hardware specs from
  module research source, dashboard communication method

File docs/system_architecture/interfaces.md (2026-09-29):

# System Interface Table

This register presents confirmed and open technical decisions across teams.
The authoritative source is `data/system_architecture/interfaces.csv` in the
repository.

!!! warning "Do not edit values in two places"
    Update the CSV source first, then synchronize this rendered table. A value
    marked **Proposed**, **Blocked**, **In Progress**, or **Conflict** is not a
    confirmed requirement.

Status meanings:

| Status | Interpretation |
|---|---|
| Confirmed | Accepted cross-team decision |
| Proposed | Candidate value requiring validation or approval |
| In Progress | Implementation or verification is incomplete |
| Blocked | A prerequisite decision or input is missing |
| Conflict | Current sources or implementations disagree |

| Category | Parameter | Value | Source Team | Status | Notes |
|---|---|---|---|---|---|
| Dimensions | Length | 800 mm | Mechanical | Confirmed |  |
| Dimensions | Width | 600 mm | Mechanical | Confirmed |  |
| Dimensions | Height | 420 mm | Mechanical | Confirmed |  |
| Mobility | Drive Type | Differential | Mechanical | Confirmed |  |
| Mobility | Caster Wheels | 4 | Mechanical | Confirmed | Changed from 2 to 4 for stability and load distribution |
| Sensors | LiDAR Count | 2 (front + rear) proposed; current integrated URDF shows a single LiDAR link | Mechanical | Needs ROS validation | Current URDF integration places one LiDAR link at front-top-centre; dual-LiDAR still not explicitly confirmed by Navigation/ROS |
| Sensors | LiDAR Coverage | 360 degrees combined if dual-LiDAR is confirmed | Mechanical | Proposed |  |
| Interface | Module Zone | 500 x 400 mm | Module Team | Confirmed |  |
| Interface | Connector Type | HARTING Han-Modular (24V power + CAN bus + Ethernet) | Module Team | Confirmed |  |
| Interface | Alignment Pins | 12 mm diameter pins on a 450 x 350 mm pattern | Module Team | Confirmed | Precise dimensions added from the module research source |
| Interface | Docking Locks | Quarter-turn M8 locks rated to 375 kg | Module Team | Confirmed | Load rating added from the module research source |
| Interface | Docking Detection | 2 inductive sensors | Module Team | Confirmed | Publishes to ROS topics `/module_docked` and `/module_id` |
| Interface | Clearance Zones | Defined around front LiDAR emergency stop and operator panel | Module Team | Confirmed | Modules cannot block these zones |
| Interface | Module Mount Frame Name | CONFLICT (now live in main): `module_interface_link` (mechanical/URDF side) vs `module_mount_top` (merged PR #8 ROS package scaffold) | Module Team + ROS/Sim Team | Conflict - needs resolution | PR #8 merged into main on 8 Jul without this being reconciled; needs an issue opened and a decision before more code/CAD builds on either name |
| Software | ROS Stack | ROS 2 Jazzy on Ubuntu 24.04 + Gazebo Harmonic (default); ROS 2 Humble + Gazebo Fortress kept as compatibility path | ROS/Sim Team | Confirmed | Locked by the approved stack update |
| Software | URDF Status | Real CAD-exported URDF integrated and spawns correctly in Gazebo | ROS/Sim + Mechanical | In Progress | Driving and `/scan` output not yet confirmed; final sensor placement pending |
| Software | Full Simulation Loop | Robot drives in warehouse world with working teleop and LiDAR/IMU/odometry publishing | ROS/Sim Team | Confirmed |  |
| Software | Module Software Scaffold | 7 ROS 2 packages: `amr_interfaces`, `arm_description`, `arm_control`, `arm_moveit_config`, `module_manager`, `task_coordinator`, `dashboard_bridge` | ROS/Sim Team | Merged into main (PR #8) | Empty-but-buildable skeleton with TODOs; see `robotics/ARCHITECTURE.md`; needs sync with this document; see conflict row above |
| Module | First Module Choice | Dual-arm robotic arm module | Module Team + ROS/Sim Team | Confirmed | Chosen collaboratively; mechanical researching arm hardware; software scaffolding arm packages |
| Module | Arm Control Framework | MoveIt2 (not Nav2) | ROS/Sim Team | Confirmed | Focus is manipulation; not mobile navigation |
| Module | CG Compensation for Dual-Arm | Approximately 30-50 mm rearward shift anticipated | Mechanical | Proposed | From the module research source; not yet validated in CAD |
| Navigation | Footprint | TBD | Navigation Team | Blocked | Real URDF now integrated; so this may resolve soon once caster layout is finalized |
| Navigation | Nav2 Configuration | Configured with placeholder footprint | Navigation Team | In Progress |  |
| Navigation | Localization | SLAM + AMCL configured; EKF config in progress | Navigation Team | Confirmed | EKF configuration is in progress |
| Power | Battery | TBD | Electrical Team | Blocked | Active research in progress |
| Power | Main Computer / Controller | TBD | Electrical Team | Blocked |  |
| Electronics | Motor Drivers | TBD | Electrical Team | Blocked |  |
| Dashboard | Communication Method | `rosbridge_server` + `roslibjs` over WebSocket bridging ROS 2 topics to the browser frontend | Dashboard Team | Confirmed - tested working | Publishes `/cmd_vel` while a directional button is held; next is subscribing to `/odom` and `/imu` |

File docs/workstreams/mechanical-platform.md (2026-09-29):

# Mechanical Platform

## Responsibility

The mechanical platform workstream defines the reusable mobile base: chassis,
mobility, internal packaging, structural support, service access, and the
physical boundary presented to functional modules.

<figure class="technical-figure">
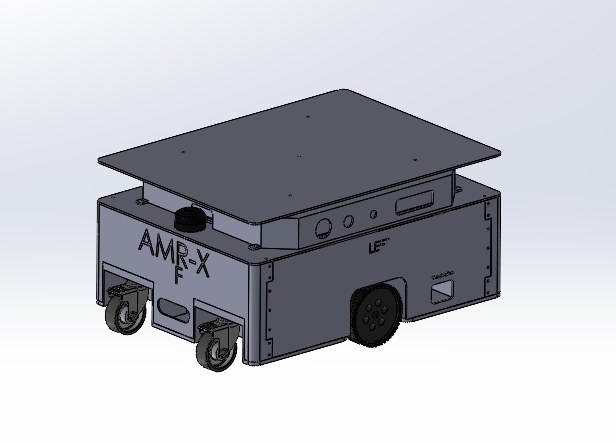
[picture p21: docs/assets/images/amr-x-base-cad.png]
AMR-X mobile base three-quarter CAD concept
  
  <figcaption><strong>Base-platform CAD concept.</strong> Use this image to communicate layout progress, not released manufacturing geometry.</figcaption>
</figure>

## Engineering activities

- Compare mobility and chassis concepts against controlled requirements.
- Maintain mass, payload, structural-load, stability, and center-of-gravity
  reasoning.
- Package the battery, compute, drivers, wiring, sensors, brakes, and service
  access without blocking safety devices or module clearance.
- Define mounting, alignment, retention, and docking geometry with the common
  interface workstream.
- Maintain CAD assemblies and approved exports with traceable revisions.

## Required interfaces

| Interface | Mechanical concern |
|---|---|
| Electrical and embedded | Component envelopes, cooling, wiring paths, connectors, access, and isolation |
| Navigation and perception | Sensor position, field of view, occlusion, footprint, and ground clearance |
| Modules | Mounting zone, loads, center of gravity, alignment, locking, and clearance |
| ROS 2 and simulation | Link geometry, joint definitions, frame locations, collision geometry, and inertial data |
| Safety | Emergency-stop access, braking provisions, guarding, maintenance, and safe handling |

## Expected outputs

- Selected base concept and conceptual CAD assembly.
- Mobility, load, stability, and packaging rationale.
- Internal layout and maintenance-access plan.
- Module-interface geometry and clearance definition.
- Simulation-ready geometry and verified frame reference points.
- Decision, risk, and validation records for unresolved mechanical choices.

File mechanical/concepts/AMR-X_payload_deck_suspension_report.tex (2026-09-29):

\documentclass[11pt,a4paper]{article}

% ---------- packages ----------
\usepackage[T1]{fontenc}
\usepackage[utf8]{inputenc}
\usepackage{amsmath}
\usepackage[margin=2.3cm]{geometry}
\usepackage[table]{xcolor}
\usepackage{booktabs}
\usepackage{array}
\usepackage{tabularx}
\usepackage{enumitem}
\usepackage{titlesec}
\usepackage{fancyhdr}
\usepackage{graphicx}
\usepackage[hidelinks]{hyperref}

% ---------- colours ----------
\definecolor{navy}{HTML}{000000}
\definecolor{accent}{HTML}{000000}
\definecolor{lightblue}{HTML}{F2F2F2}
\definecolor{lightgreen}{HTML}{E8E8E8}
\definecolor{amber}{HTML}{ECECEC}
\definecolor{greyln}{HTML}{808080}

% ---------- section styling ----------
\titleformat{\section}{\Large\bfseries\color{navy}}{\thesection.}{0.6em}{}[{\color{accent}\titlerule[1pt]}]
\titleformat{\subsection}{\large\bfseries\color{black!80}}{\thesubsection}{0.6em}{}
\titlespacing*{\section}{0pt}{14pt}{6pt}

% ---------- header / footer ----------
\pagestyle{fancy}\fancyhf{}
\renewcommand{\headrulewidth}{0.3pt}
\lhead{\small\color{navy}AMR-X Prototype V1}
\rhead{\small\color{navy}Payload-Deck Suspension Study}
\cfoot{\small\color{black!55}Page \thepage}

\newcolumntype{Y}{>{\raggedright\arraybackslash}X}
\newcommand{\prio}[1]{\colorbox{amber}{\parbox{\dimexpr\linewidth-2\fboxsep}{#1}}}

\setlist[itemize]{leftmargin=1.3em,itemsep=2pt,topsep=3pt}

% ---------- title ----------
\begin{document}
\begin{titlepage}
\thispagestyle{empty}
\vspace*{2.2cm}
\noindent\rule{\linewidth}{1.2pt}\\[10pt]
{\small\bfseries\color{black} AMR-X PROTOTYPE V1 \quad$\cdot$\quad MECHANICAL ENGINEERING}\\[14pt]
{\color{black}\Huge\bfseries Payload-Deck Suspension}\\[8pt]
{\color{black}\Large Shock Isolation for the Payload Plate: Options, Trade-offs, Recommendation and Procurement}\\[12pt]
\noindent\rule{\linewidth}{0.5pt}\\[10pt]
{\normalsize 100\,kg payload \quad$\cdot$\quad 600--800\,mm deck plate \quad$\cdot$\quad impact-dominated duty \quad$\cdot$\quad vibration + curb-drop secondary}
\vfill
\noindent\rule{\linewidth}{0.5pt}\\[4pt]
{\footnotesize Engineering design report \hfill Revision 1}
\end{titlepage}

% =====================================================================
\section*{List of Abbreviations}
\begin{center}\small
\renewcommand{\arraystretch}{1.25}
\begin{tabularx}{\linewidth}{@{}p{2.3cm}Y@{}}
\toprule
\textbf{Abbreviation} & \textbf{Meaning} \\
\midrule
AMR & Autonomous Mobile Robot \\
AMR-X & Designation of this prototype platform (the robot studied in this report) \\
AGV & Automated Guided Vehicle \\
\rowcolor{lightblue} WRI & Wire Rope Isolator (looped stranded-cable shock/vibration mount) \\
PU & Polyurethane (elastomer / wheel material) \\
\rowcolor{lightblue} CoG & Centre of Gravity \\
RFQ & Request for Quotation \\
\rowcolor{lightblue} MOQ & Minimum Order Quantity \\
NVH & Noise, Vibration and Harshness \\
\rowcolor{lightblue} USPTO & United States Patent and Trademark Office \\
MIL-STD & United States Military Standard (e.g.\ MIL-STD-810 environmental) \\
\midrule
\multicolumn{2}{@{}l}{\textit{Units}} \\
N / kN & Newton / kilonewton (force) \\
\rowcolor{lightblue} J & Joule (energy) \\
kg & Kilogram \\
\rowcolor{lightblue} mm & Millimetre \\
Hz & Hertz (natural frequency) \\
\rowcolor{lightblue} g & Acceleration relative to gravity ($\approx$9.81\,m/s$^2$) \\
m/s & Metres per second \\
\bottomrule
\end{tabularx}
\end{center}

% =====================================================================
\section{Why this question exists}
The payload deck currently bolts \textbf{rigidly} to the lift/frame. That is fine until the moment a
$\approx$100\,kg payload is \emph{set down} on it. The kinetic energy of that placement has to go
somewhere, and on a rigid deck it goes straight into the frame, the fasteners and the lift mechanism as
a sharp force spike.

The governing relation is simple and unforgiving:
\[
\textbf{peak force into the frame} \;\approx\; \frac{\text{impact energy}}{\text{stroke}}.
\]
A feel for the numbers: 100\,kg arriving with even $\approx$25\,mm of drop is $\approx$25\,J. Absorbed
over 25\,mm of suspension travel that averages $\approx$1\,kN ($\approx$100\,kgf). Absorbed over the
1--2\,mm of ``give'' a rigid bolted deck has, the same 25\,J becomes \textbf{12--25\,kN} slammed into the
structure. Interposing controlled travel buys an order-of-magnitude ($\approx$10$\times$) reduction in
peak force. \textbf{That force reduction --- not ride comfort --- is the whole point of this mechanism.}

\textbf{The duty, in priority order.}
\begin{itemize}
\item \textbf{Primary: placement shock.} Protect the robot when the payload lands on the deck.
\item \textbf{Secondary: floor vibration and curb drops} transmitted up through the chassis while driving.
\end{itemize}

\textbf{The catch a spring alone cannot solve.} A pure spring (rubber, coil or air) \emph{stores} the
placement energy and throws it straight back --- the payload bounces and you get repeated impacts. For
placement shock the mechanism must \textbf{dissipate} energy, not just deflect. This single fact drives
the entire ranking that follows.

\textbf{Design target.} Impact-dominated, with the payload varying $0\rightarrow100$\,kg every cycle, on
an indoor warehouse floor (small repeated unevenness --- joints, ramps, dock-plate lips --- not rough
terrain). Crucially the deck must still present a \emph{repeatable height} for docking and pick/place;
production AMRs in this class hold $\approx\pm5$\,mm positioning, and AGV practice warns that an
unconstrained compliant deck ``floats'' its height and breaks dock/sensor alignment~\cite{abb,casterhq}.
The real question is therefore: \textbf{how do we put controlled, damped travel between deck and frame
without losing deck-height repeatability.}

% =====================================================================
\section{Candidate mechanisms}
Six approaches span the spectrum from doing nothing to a fully guided, damped platform.

\begin{center}\small
\renewcommand{\arraystretch}{1.25}
\begin{tabularx}{\linewidth}{@{}p{3.5cm}Y c c c@{}}
\toprule
\textbf{Option} & \textbf{How it works} & \textbf{Energy handling} & \textbf{Complexity} & \textbf{Fit} \\
\midrule
A. Rigid deck & plate bolted hard to frame & Poor (no stroke) & Lowest & Gentle hand-loading only \\
B. Elastomeric mounts & rubber sandwich/cone pads & Fair; rebounds & Low & Vibration, light shock \\
C. Coil-spring isolators & steel springs in housings & Fair; stores \& rebounds & Low & Low-freq vibration \\
D. Air springs / pneumatic & rubber bellows on air & Good vibration; needs air & Med & Vibration isolation \\
\rowcolor{lightgreen} E. Wire rope isolators & looped cable, high internal (hysteretic) damping & Good; damps, low rebound & Low & \textbf{Our case} \\
\rowcolor{lightgreen} F. Guided deck + hydraulic damper & plate on linear guides + shock absorbers & Excellent; near-zero rebound & Med--High & \textbf{Our case (worst drops)} \\
\bottomrule
\end{tabularx}
\end{center}

\noindent\textbf{The two that fit us are E and F.}
\textbf{E} (wire rope isolators) puts high energy absorption per millimetre of travel into a single
bolt-on metal part: the cable strands rub and dissipate the impact instead of springing it back, and the
same part also covers the secondary vibration and curb-drop duty in all three axes. \textbf{F} (a plate
on linear guides with hydraulic shock absorbers) gives the cleanest possible \emph{no-rebound} stop for
genuine drops, because a hydraulic damper converts the impact almost entirely to heat at a near-constant
low force. In practice the two combine well --- wire rope isolators as the primary mounts, with a rubber
end-stop, or the guided-deck variant when loads are dropped rather than placed.

Options B, C and D are kept as the \emph{vibration} layer, not the impact layer: a single-rate rubber,
coil or air spring sized to catch a 100\,kg drop is far too stiff when the deck is empty, and rubber can
take a set or tear under repeated heavy impacts.

% =====================================================================
\section{Real-product precedents}
\textbf{Option E --- wire rope isolators.}
These are the defence- and aerospace-standard answer to \emph{repeated} shock precisely because they
damp in all three axes, are unaffected by oil, temperature and ageing, and are maintenance-free; the
standard catalogue lines are qualified to environmental standards such as MIL-STD-810~\cite{enidine}.
The recurring design rule is to mount them at $\approx 45^{\circ}$ to the load, which equalises the
stiffness across all three axes so one part handles the vertical placement shock \emph{and} the
horizontal curb/stop loads~\cite{uspto45a,uspto45b}. The category is already used in automated-warehouse
equipment~\cite{enidine}.

\textbf{Option F --- guided deck with hydraulic shock absorbers.}
Industrial self-compensating shock absorbers convert impact to heat and do not rebound. The decisive
feature for us is that the payload energy changes every cycle as the load varies $0\rightarrow100$\,kg,
and self-compensating units ``react to changing energy conditions without adjustment'', covering
effective weights from $\approx$1\,kg to 1{,}550\,kg with a side-load adapter for impact angles up to
$25^{\circ}$~\cite{acesc,aceheavy}. Mounted under a linearly-guided plate with light return springs,
they form the no-bounce drop-catcher of Solution~F.

\textbf{Why not a bare spring.}
Coil, rubber and air mounts are excellent \emph{vibration} isolators --- air springs in particular reach
very low natural frequencies~\cite{firestone,mason} --- but used alone for placement shock they store the
energy and bounce the load. And on an AGV/AMR specifically, soft unconstrained compliance under the deck
varies the deck height and ``breaks sensor and dock-plate alignment'', which is why such compliance is
normally reserved for manual carts unless its travel is constrained~\cite{casterhq}.

% =====================================================================
\section{Recommendation: Solution E (wire rope isolators)}
\textbf{We recommend Solution~E} --- mounting the deck plate on wire rope isolators at the four corners.
It attacks our exact failure mode (placement energy spiking into the frame) at the source, it damps
rather than rebounds, and it delivers the primary \emph{and} both secondary duties in one
maintenance-free, bolt-on metal part with no air supply or power. It is also the only one of the two
fitting options available as a \emph{finished, purchasable component}, which de-risks and accelerates the
prototype.

\subsection{The trade-off you must accept}
\prio{\textbf{A compliant deck trades structural protection against deck-height repeatability.}
The same travel that protects the frame also lets the deck move under load, so dock/pick height can drift
and the payload can sway in turns. Accept this by \textbf{constraining the travel}: hard limit stops plus
a rubber end-stop, modest stroke ($\sim$15--25\,mm), and isolators placed symmetrically about the payload
CoG so each corner carries an equal $\approx$25\,kg share. If a \emph{precise} docking height is required,
decouple the two needs in time --- soft-isolate while driving, then mechanically lock or clamp the deck
during pick/place and docking.}

\medskip
\noindent If loads can be genuinely \emph{dropped} (not gently lowered), step up to Solution~F: a guided
deck on linear bearings with hydraulic self-compensating absorbers and light return springs. It gives the
cleanest no-rebound stop, but --- like a fabricated rocker in the drivetrain study --- it is an
\emph{assembly}, not a single purchasable kit.

% =====================================================================
\section{Specifications to preserve or improve}
Any deck-suspension solution must \textbf{meet or beat} the rigid baseline on the points below. Targets
derived from the impact and packaging study:

\begin{center}\small
\renewcommand{\arraystretch}{1.25}
\begin{tabularx}{\linewidth}{@{}p{5.0cm}p{4.0cm}Y@{}}
\toprule
\textbf{Parameter} & \textbf{Current (rigid deck)} & \textbf{Requirement} \\
\midrule
Static payload & 100\,kg & support 100\,kg + dynamic margin \\
Per-corner static load & $\approx$25\,kg (4 mounts) & isolator at $\sim$50\% of rating (shock headroom) \\
Vertical travel & $\approx$0 (rigid) & $\sim$15--25\,mm \emph{controlled}, with hard stops \\
Peak force into frame & 12--25\,kN on a drop & cut $\approx$10$\times$ by adding stroke \\
Rebound after placement & n/a & damped, no bounce (dissipative) \\
Load variability & n/a & cope $0\rightarrow100$\,kg per cycle \\
Deck-height repeatability & fixed by bolt-up & maintain for docking (limit stops / lock) \\
Environment & indoor warehouse & oil/temp/age-stable, maintenance-free \\
\bottomrule
\end{tabularx}
\end{center}

\noindent A 4-corner wire rope set clears these with margin; the items needing active confirmation in the
RFQ are the \textbf{drop height / placement velocity} (which fixes the energy and therefore the isolator
size and count) and the \textbf{travel-limit / end-stop} scheme that protects deck-height repeatability.

% =====================================================================
\section{Ready-to-buy products suited to our use case}
The following are appropriate for a 100\,kg payload deck (with the noted configuration). All are
catalogue parts with low MOQ.

\begin{center}\small
\renewcommand{\arraystretch}{1.3}
\begin{tabularx}{\linewidth}{@{}p{3.2cm}Y p{2.5cm}@{}}
\toprule
\textbf{Product} & \textbf{Why it fits us / what to configure} & \textbf{Type} \\
\midrule
\rowcolor{lightblue}
Enidine WR6-700-10~\cite{wr6} &
$\approx$50.8\,kg/unit, $\approx$43\,mm tall. Four corners at $45^{\circ}$; at 25\,kg/corner it sits at
$\sim$50\% rating, leaving compression travel for the impact. \textbf{Primary pick.} & Wire rope isolator \\
Enidine WR8-400-08~\cite{wr8} &
$\approx$68.9\,kg/unit, $\approx$54\,mm tall. Step up to this (or run six WR6) if placement drops are
harsh. & Wire rope isolator \\
\rowcolor{lightblue}
ACE SC$^2$ self-compensating absorbers~\cite{acesc} &
Effective weight 1--1{,}550\,kg, side-load adapter to $25^{\circ}$, self-compensates as load varies
$0\rightarrow100$\,kg. The energy dump for Solution~F. & Hydraulic damper \\
Parker LORD Flex-Bolt sandwich (small group)~\cite{lord} &
$\approx$3--66\,kg/mount; cheap, simple vibration layer to add beneath/alongside the primary mounts. &
Elastomeric mount \\
ACE PAL-3~\cite{acepal} &
Auto-levelling air spring, $\leq$385\,kg/spring; adds constant deck level + isolation if levelling is
needed (requires air). & Pneumatic levelling \\
\rowcolor{lightblue}
PGFUN 10-loop WRI~\cite{pgfun} &
Low-cost 10-loop stainless isolators to validate geometry before committing to engineered units. \emph{Prototype only.} & Wire rope (proto) \\
\bottomrule
\end{tabularx}
\end{center}

\noindent\textbf{Primary picks for us:} \textbf{4$\times$ Enidine WR6-700-10} (or six, or step to WR8 for
harsh drops), mounted at $45^{\circ}$ with a rubber end-stop, because they damp the placement impact,
cover vibration and curb drops in the same part, need no air or power, and are maintenance-free. The
single open point is the \textbf{exact size/count}, which the supplier sizing tool fixes once the drop
height is known. Hold \textbf{Solution~F (guided deck + ACE SC$^2$)} as the upgrade for true drop loading.

% =====================================================================
\section{Priority of this modification}
\prio{\textbf{Priority: MEDIUM now, rising to HIGH before any payload-handling trials.}}

\begin{itemize}
\item \textbf{Not a bring-up blocker.} An empty or gently hand-loaded deck on a rigid mount is fine for
powering up the robot and validating electronics, navigation and the safety chain. It does not gate first
motion.
\item \textbf{Becomes critical for payload operations.} Once the robot does automated or repeated payload
placement --- and once it drives a real floor with joints, dock-plates and curb lips --- the rigid deck
funnels every placement and curb impact straight into the frame, fasteners and lift mechanism, where
repeated multi-kN spikes drive fatigue and shock the electronics. This must be resolved before field
trials.
\item \textbf{Ranking against other open items.} It sits \emph{below} the chassis-geometry and drivetrain
decisions that determine whether the platform can be built at all, but it \emph{interacts with the lift
mechanism} the deck mounts to --- so the suspension interface must be fixed together with the lift, not
bolted on afterwards.
\end{itemize}

\noindent\textbf{Recommended action:} issue an RFQ / order for 4--8$\times$ Enidine WR6-700-10 (confirm
exact part and count via the supplier sizing tool once drop height/velocity is measured), mount them at
$45^{\circ}$ with hard limit stops and a rubber end-stop, and keep the guided-deck + ACE SC$^2$ assembly
(Solution~F) as the fallback for genuine drop loading.

% =====================================================================
\begin{thebibliography}{99}
\small
\bibitem{abb} ABB. \textit{AMR P603V Product Specification} (3HKA00000226401) --- lift-type AMR; deck
raised on ball-screw lifters; positioning to $\approx\pm5$\,mm; on-deck load-measurement sensors.
\bibitem{enidine} Enidine (ITT). \textit{Wire Rope Isolators} --- stainless cable, RoHS aluminium bars;
qualified to MIL-STD-810, BV43-44, MIL-STD-167 and similar; used in automated-warehouse equipment.
\url{https://www.enidine.com/en-us/products/wire-rope-isolators}
\bibitem{uspto45a} USPTO. \textit{Multi-axis shock and vibration isolation system}, US~6,530,563
(wire rope isolators at $\approx 45^{\circ}$ to the suspended mass for balanced three-axis stiffness).
\url{https://image-ppubs.uspto.gov/dirsearch-public/print/downloadPdf/6530563}
\bibitem{uspto45b} USPTO. \textit{Shock resistant device}, US~7,260,476 (mounting wire rope isolators at
$\approx 45^{\circ}$ equalises compression/shear/roll stiffness and extends life).
\url{https://image-ppubs.uspto.gov/dirsearch-public/print/downloadPdf/7260476}
\bibitem{acesc} ACE Controls. \textit{SC$^2$ Self-Compensating Industrial Shock Absorbers} --- effective
weight 1--1{,}550\,kg, integrated positive stop, side-load adapter to $25^{\circ}$, react to changing
energy without adjustment. \url{https://www.acecontrols.com/us/}
\bibitem{aceheavy} ACE Controls / Valin. \textit{Heavy / self-compensating industrial shock absorbers}
(self-compensating units react to changing energy conditions without adjustment).
\url{https://www.valin.com/motion-control-and-automation/products/heavy-industrial-shock-absorbers-ace-controls-inc}
\bibitem{wr6} Enidine. \textit{WR6-700-10 wire rope isolator datasheet} (load capacity $\approx$50.8\,kg
/ 112\,lb; thickness $\approx$43\,mm).
\url{https://datasheets.globalspec.com/ds/itt-inc/wr6-700-10/36ff8e41-4c53-43df-81f6-df1d272cb7a7}
\bibitem{wr8} Enidine. \textit{WR8-400-08 wire rope isolator datasheet} (load capacity $\approx$68.9\,kg
/ 152\,lb; thickness $\approx$54\,mm).
\url{https://datasheets.globalspec.com/ds/itt-inc/wr8-400-08/07d5da4c-76cb-48fa-be8d-d096f6d5a05b}
\bibitem{lord} Parker LORD. \textit{Flex-Bolt Sandwich Mounts} (small group $\approx$31--645\,N
$\approx$3--66\,kg per mount; metric thread).
\url{https://www.modusadvanced.com/parker-lord-vibration-isolation-mounts}
\bibitem{firestone} Firestone Industrial. \textit{Airstroke / Airmount Engineering Manual \& Design Guide}
(air-spring isolators; highest isolation of any type; no spring chatter).
\url{https://www.firestoneairide.com/content/dam/fsip/pdfs/airstroke/Actuators-and-Isolators-Metric-Design-Guide.pdf}
\bibitem{acepal} ACE Controls. \textit{PAL-3 to PAL-9 low-frequency pneumatic levelling mounts}
(automatic level control; up to 385\,kg per air spring; natural frequency to $\sim$1.7\,Hz).
\url{https://www.acecontrols.com/us/products/vibration-control/low-freq-pneumatic-levelling-mounts.html}
\bibitem{mason} Mason Industries. \textit{Spring Isolators / housed spring mounts} (steel-coil low-frequency
vibration mounts; horizontal stiffness drops with deflection --- add limit stops).
\url{https://mason-ind.com/spring-isolators/}
\bibitem{casterhq} CasterHQ. \textit{Spring-loaded casters --- AGV guidance} (sprung compliance under a
deck introduces variable deck height that breaks sensor / dock-plate alignment unless travel is constrained).
\url{https://casterhq.com/collections/casters-spring-loaded}
\bibitem{pgfun} PGFUN. \textit{10-loop 304 stainless wire rope isolator} (low-cost prototype isolators;
more loops give better cushioning).
\url{https://www.amazon.com/PGFUN-Isolator-Stainless-Anti-Vibration-Absorber/dp/B09W695DJ6}
\end{thebibliography}

\end{document}

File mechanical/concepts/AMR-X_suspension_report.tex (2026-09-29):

\documentclass[11pt,a4paper]{article}

% ---------- packages ----------
\usepackage[T1]{fontenc}
\usepackage[utf8]{inputenc}
\usepackage[margin=2.3cm]{geometry}
\usepackage[table]{xcolor}
\usepackage{booktabs}
\usepackage{array}
\usepackage{tabularx}
\usepackage{enumitem}
\usepackage{titlesec}
\usepackage{fancyhdr}
\usepackage{graphicx}
\usepackage[hidelinks]{hyperref}

% ---------- colours ----------
\definecolor{navy}{HTML}{000000}
\definecolor{accent}{HTML}{000000}
\definecolor{lightblue}{HTML}{F2F2F2}
\definecolor{lightgreen}{HTML}{E8E8E8}
\definecolor{amber}{HTML}{ECECEC}
\definecolor{greyln}{HTML}{808080}

% ---------- section styling ----------
\titleformat{\section}{\Large\bfseries\color{navy}}{\thesection.}{0.6em}{}[{\color{accent}\titlerule[1pt]}]
\titleformat{\subsection}{\large\bfseries\color{black!80}}{\thesubsection}{0.6em}{}
\titlespacing*{\section}{0pt}{14pt}{6pt}

% ---------- header / footer ----------
\pagestyle{fancy}\fancyhf{}
\renewcommand{\headrulewidth}{0.3pt}
\lhead{\small\color{navy}AMR-X Prototype V1}
\rhead{\small\color{navy}Drive-Wheel Suspension Study}
\cfoot{\small\color{black!55}Page \thepage}

\newcolumntype{Y}{>{\raggedright\arraybackslash}X}
\newcommand{\prio}[1]{\colorbox{amber}{\parbox{\dimexpr\linewidth-2\fboxsep}{#1}}}

\setlist[itemize]{leftmargin=1.3em,itemsep=2pt,topsep=3pt}

% ---------- title ----------
\begin{document}
\begin{titlepage}
\thispagestyle{empty}
\vspace*{2.2cm}
\noindent\rule{\linewidth}{1.2pt}\\[10pt]
{\small\bfseries\color{black} AMR-X PROTOTYPE V1 \quad$\cdot$\quad MECHANICAL ENGINEERING}\\[14pt]
{\color{black}\Huge\bfseries Drive-Wheel Suspension}\\[8pt]
{\color{black}\Large Options, Trade-offs, Recommendation and Procurement}\\[12pt]
\noindent\rule{\linewidth}{0.5pt}\\[10pt]
{\normalsize 2-drive / 4-caster differential AMR \quad$\cdot$\quad 130\,kg design load \quad$\cdot$\quad 24\,V \quad$\cdot$\quad 0.8--1.5\,m/s}
\vfill
\noindent\rule{\linewidth}{0.5pt}\\[4pt]
{\footnotesize Engineering design report \hfill Revision 1}
\end{titlepage}

% =====================================================================
\section*{List of Abbreviations}
\begin{center}\small
\renewcommand{\arraystretch}{1.25}
\begin{tabularx}{\linewidth}{@{}p{2.3cm}Y@{}}
\toprule
\textbf{Abbreviation} & \textbf{Meaning} \\
\midrule
AMR & Autonomous Mobile Robot \\
AMR-X & Designation of this prototype platform (the robot studied in this report) \\
AGV & Automated Guided Vehicle \\
\rowcolor{lightblue} PU & Polyurethane (caster/wheel tyre material) \\
RFQ & Request for Quotation \\
\rowcolor{lightblue} SIL & Safety Integrity Level (functional-safety classification, IEC\,61508) \\
PLd & Performance Level d (functional-safety rating, ISO\,13849) \\
\rowcolor{lightblue} CoG & Centre of Gravity \\
EC & Electronically Commutated --- brushless motor family (e.g.\ Maxon EC\,45) \\
\rowcolor{lightblue} GP & Gearhead, Planetary --- gearbox family (e.g.\ Maxon GP\,42C) \\
USPTO & United States Patent and Trademark Office \\
\rowcolor{lightblue} IEEE & Institute of Electrical and Electronics Engineers \\
IROS & International Conference on Intelligent Robots and Systems \\
\midrule
\multicolumn{2}{@{}l}{\textit{Units}} \\
V & Volt \\
\rowcolor{lightblue} W & Watt \\
N & Newton \\
\rowcolor{lightblue} Nm / mNm & Newton-metre / milli-newton-metre \\
kg & Kilogram \\
\rowcolor{lightblue} mm & Millimetre \\
m/s & Metres per second \\
\bottomrule
\end{tabularx}
\end{center}

% =====================================================================
\section{Why this question exists}
The layout uses \textbf{six ground contacts}: two central drive wheels plus four corner casters.
On a rigid frame that is one contact too many. Any three points define a plane, so a rigid
six-contact base behaves like a four-legged table on an uneven floor: it rocks, and whichever
contacts lift stop carrying load.

For a differential drive this is not cosmetic. Steering depends on \emph{both} drive wheels being
firmly pressed to the floor. If one unloads on an expansion-joint seam or a dock-plate lip, the wheel
slips, the robot yaws unpredictably, odometry drifts, and — with our payload centre of gravity up at
$\approx$398\,mm — the rocking is amplified. The real question is therefore not ``do we want a fancy
suspension'' but \textbf{how do we guarantee all six contacts stay loaded on a real warehouse floor.}

\textbf{Design target.} Production AMRs in this class (e.g.\ MiR) publish a traversable floor-gap
tolerance of $\approx$30\,mm at $\approx$27\,mm ground clearance~\cite{mir}. That confirms the target:
small, repeated unevenness (joints, ramps, thresholds), \emph{not} rough terrain.

% =====================================================================
\section{Candidate mechanisms}
Six approaches span the spectrum from doing nothing to full rover suspension.

\begin{center}\small
\renewcommand{\arraystretch}{1.25}
\begin{tabularx}{\linewidth}{@{}p{3.3cm}Y c c c@{}}
\toprule
\textbf{Option} & \textbf{How it works} & \textbf{Traction} & \textbf{Complexity} & \textbf{Fit} \\
\midrule
A. Rigid & all wheels bolted hard to frame & Poor & Lowest & Flat floor only \\
B. Sprung casters & springs on the corner casters & Fair & Low & Light robots \\
\rowcolor{lightgreen} C. Sprung drive units & each drive wheel on a pre-loaded spring/slide ($\sim$15--25\,mm travel) & Good & Low--Med & \textbf{Our case} \\
\rowcolor{lightgreen} D. Transverse rocker & both drive units on one central pivot beam (see-saw) & Good & Low & \textbf{Our case} \\
E. Independent arms & each drive wheel on its own sprung swing-arm & Very good & Med--High & Uneven floors \\
F. Rocker-bogie & linked rockers + body differential (Mars rover) & Excellent & High & Rough terrain (overkill) \\
\bottomrule
\end{tabularx}
\end{center}

\noindent\textbf{The two that fit us are C and D.}
\textbf{C} (sprung drive units) directly guarantees a constant downward force on each drive wheel, so
traction is maintained over seams and ramps and the payload is isolated from jolts. \textbf{D}
(transverse rocker) is the simplest passive way to keep \emph{both} drive wheels loaded: when one
rises, the beam rocks and the other is pushed down by the same amount. In practice the two are often
combined --- a sprung drive pod mounted on a rocker.

% =====================================================================
\section{Real-robot precedents}
\textbf{Option C --- sprung drive wheels.}
The \textbf{iRobot Roomba} is the textbook case: each differential drive wheel is a self-contained
spring-loaded module (motor + gearbox + spring) that compresses and extends independently to keep
floor contact; the design rationale is exactly ours --- losing drive-wheel contact loses steering
accuracy~\cite{ifixit,sevarg}. At our scale, AMR patent \textbf{US~12,128,554} places the drive units
on coil springs and linear bearings with a $\approx$25\,mm stroke and couples both wheels (``parallel''
suspension) to keep the track width constant and stay narrow-aisle compact~\cite{patentC}.
\textbf{MiR} AMRs use a central differential drive whose published gap/clearance figures only make
sense with loaded/sprung drive wheels~\cite{mir}.

\textbf{Option D --- rocker / equalizer.}
The Mars-rover rocker-bogie is the most-illustrated example of the pivot principle: if one wheel goes
up, the linked wheel is forced down by the same amount~\cite{planetary}. AMR driving-module patents use
the same single-pivot ``rocker'' idea in a compact drive unit~\cite{patentD}. We need only the
\emph{single central rocker}, not the full bogie.

% =====================================================================
\section{Recommendation: Solution C (sprung drive units)}
\textbf{We recommend Solution~C} --- placing each drive wheel on its own pre-loaded spring suspension.
It is the mechanism the field converges on for indoor differential AMRs because it attacks our exact
failure mode (a drive wheel unloading) at the source, isolates the electronics and payload from floor
shock, and --- unlike a bare rocker --- gives a known, repeatable wheel load that can be tuned to our
65\,kg-per-wheel share. It is also the only one of the two available as a \emph{finished, bolt-on
product} (Section~6), which de-risks and accelerates a prototype.

\subsection{The trade-off you must accept}
\prio{\textbf{Buying Solution C as a ready module means replacing the Maxon EC\,45 flat + GP\,42C.}
The off-the-shelf ``AGV suspension drive wheel'' is sold as a sealed assembly --- wheel + gearbox +
\emph{motor} + encoder + spring (sometimes brake and controller) --- all dimensioned around \emph{its own}
motor. There is no slot to insert the EC\,45. So adopting a ready C-module retires our discrete
motor/gearbox selection. The upside: these modules use 400\,W-class motors, which \emph{exceed} the
2$\times$70\,W Maxon set-up --- so torque and power go \emph{up}, not down (see Section~5--6).}

\medskip
\noindent If keeping the EC\,45 + GP\,42C is mandatory, Solution~C must instead be \emph{fabricated}
(a sprung vertical linear slide per drive unit, built from catalogue linear guides + springs), or
Solution~D (a fabricated rocker) is used --- both keep the Maxon and all dimensions, but neither is a
single purchasable kit.

% =====================================================================
\section{Specifications to preserve or improve}
Any replacement module must \textbf{meet or beat} the current drivetrain. Targets derived from the
sizing study:

\begin{center}\small
\renewcommand{\arraystretch}{1.25}
\begin{tabularx}{\linewidth}{@{}p{5.2cm}p{4.3cm}Y@{}}
\toprule
\textbf{Parameter} & \textbf{Current (EC\,45 + GP\,42C)} & \textbf{Requirement for a kit} \\
\midrule
Supply voltage & 24\,V & 24\,V (match battery) \\
Max speed & 1.5\,m/s (33:1 gives 2.85 top) & $\geq$1.5\,m/s \\
Continuous tractive force (pair) & $\approx$69\,N & $\geq$69\,N; $\geq$100\,N desired for ramps \\
Continuous torque (per motor) & 130\,mNm~\cite{maxon} & meet/exceed at the wheel \\
Wheel diameter & \O180\,mm & \O180\,mm to preserve geometry \\
Per-wheel load (spring tuning) & $\approx$65\,kg & spring rated/tuned for $\sim$65\,kg/wheel \\
Encoder & yes (Hall / E6B2) & integrated encoder \\
\bottomrule
\end{tabularx}
\end{center}

\noindent A 400\,W-class integrated drive wheel clears the speed, torque and power targets with margin
(``better''); the two items that need active confirmation are \textbf{24\,V} availability and a
\textbf{spring rate tuned to our light 65\,kg/wheel} (most modules are built for far heavier robots, so
an untuned spring can be too stiff to deflect).

% =====================================================================
\section{Ready-to-buy kits (Solution C) suited to our use case}
The following provide drive + suspension in one unit and are appropriate (with the noted configuration)
for a 130\,kg indoor AMR. All are customisable with low minimum order quantity.

\begin{center}\small
\renewcommand{\arraystretch}{1.3}
\begin{tabularx}{\linewidth}{@{}p{3.0cm}Y p{2.6cm}@{}}
\toprule
\textbf{Product} & \textbf{Why it fits us / what to configure} & \textbf{Suspension} \\
\midrule
\rowcolor{lightblue}
ZHLUN Robotic Drive Unit (electric differential wheel)~\cite{zhlun} &
Bundles motor, encoder, reducer, controller and PU wheel; two-stage damping (coil spring + PU block).
Request 24\,V, \O180 wheel, $\geq$1.5\,m/s, spring tuned to 65\,kg/wheel. & Spring + PU block (built in) \\
TZBOT AGV Suspension Drive Wheel~\cite{tzbot} &
Dedicated suspension differential unit; select the \emph{smallest} model (the TZCS heavy-load variants
are 4-tonne class --- avoid). Confirm 24\,V and wheel \O. & Spring suspension (built in) \\
\rowcolor{lightblue}
BeUDMKE Shock-Absorbing Drive Wheel~\cite{dmk} &
One-stop wheel + motor + driver + gearbox with shock absorption; customisable voltage, wheel \O\ and
ratio. & Shock-absorbing (built in) \\
ez-Wheel SWD\,125~\cite{ezwheel} &
24\,V integrated \emph{safety} wheel drive purpose-built for AMRs (SIL2/PLd), encoder included ---
strong on functional safety. Note: \O125 wheel (changes ride height) and confirm whether compliance is
built in or added. & Integrated drive (verify) \\
Bosch Rexroth ROKIT Motor~\cite{rokit} &
Premium plug-and-drive wheel (wheel, gearbox, brake, motor, encoder, controller). Pallet-scale ---
likely oversized; rigid, so pair with compliance. Reference-grade fallback. & Rigid (add compliance) \\
\bottomrule
\end{tabularx}
\end{center}

\noindent\textbf{Primary picks for us:} the \textbf{ZHLUN} and \textbf{BeUDMKE} suspension drive wheels,
because they explicitly include the spring/PU compliance (true Solution~C), are customisable to 24\,V /
\O180 / $\geq$1.5\,m/s, and carry far more than 65\,kg so the motor specs land \emph{above} ours. The
single open point on both is spring tuning for our light per-wheel load --- specify it in the RFQ.

% =====================================================================
\section{Priority of this modification}
\prio{\textbf{Priority: MEDIUM now, rising to HIGH before any real-floor deployment.}}

\begin{itemize}
\item \textbf{Not a bring-up blocker.} On a flat lab/test floor a rigid mount runs; the robot can be
powered up, driven and have its electronics, navigation and safety chain validated \emph{before} the
suspension is fitted. So it does not gate first motion.
\item \textbf{Becomes critical for deployment.} On any production floor with expansion joints,
dock-plates or ramps, the over-constrained six-contact base \emph{will} rock and intermittently unload a
drive wheel --- degrading traction, odometry and stability (worsened by the high CoG). Before field
trials this must be resolved.
\item \textbf{Ranking against other open items.} It sits \emph{below} the two hard geometric conflicts
that decide whether the chassis can be built at all --- the battery pack aspect ratio vs.\ the motors,
and the caster mount height vs.\ the 40\,mm ground clearance --- and below freezing the drivetrain
torque (the 33:1 $\rightarrow$ 51:1 ratio question). Resolve those first; schedule the suspension
decision immediately after, because choosing a ready C-module \emph{is} the drivetrain decision (it
replaces the motor) and therefore should not be left late.
\end{itemize}

\noindent\textbf{Recommended action:} issue an RFQ to ZHLUN and BeUDMKE for their smallest 24\,V
suspension differential drive wheel (\O180, $\geq$1.5\,m/s, encoder, spring tuned to $\sim$65\,kg/wheel),
and in parallel keep the fabricated rocker (Solution~D around the existing Maxon) as the fallback that
changes no specification and no dimension.

% =====================================================================
\begin{thebibliography}{99}
\small
\bibitem{maxon} maxon group. \textit{EC\,45 flat \O45\,mm brushless, 70\,W} — product/datasheet
(max.\ continuous torque 130\,mNm, up to 85\% efficiency, 24\,V winding).
\url{https://www.maxongroup.com/}
\bibitem{ifixit} iFixit. \textit{Roomba 650 Wheel Module Disassembly} (identifies the suspension pivot
pin). \url{https://www.ifixit.com/Guide/Roomba+650+wheel+module+Disassembly/97733}
\bibitem{sevarg} Sevarg. \textit{Roomba i7 Teardown} (drive module = motor + geartrain + suspension
spring, with large travel). \url{https://www.sevarg.net/2018/12/30/roomba-i7-teardown-with-the-waving-cat/}
\bibitem{patentC} USPTO. \textit{Autonomous mobile robot with a single modular platform},
US~12,128,554 (coil-spring drive units on linear bearings, $\approx$25\,mm stroke, parallel suspension).
\bibitem{patentD} USPTO. \textit{Driving module of autonomous mobile robot}, US~12,194,800
(single-pivot rocker drive unit). 
\bibitem{planetary} The Planetary Society. \textit{How the Mars rover rocker-bogie suspension works}
(``if the left front wheel goes up, the right front wheel is forced down by the same amount'').
\url{https://www.planetary.org/}
\bibitem{mir} Mobile Industrial Robots. \textit{MiR600 specifications} (ground clearance $\approx$27\,mm;
traversable floor gap up to $\approx$30\,mm). \url{https://www.mobile-industrial-robots.com/}
\bibitem{zhlun} ZHLUN / Guangzhou Wisdom Wheel. \textit{Robotic Drive Units — Electric Differential
Wheel} (two-stage spring + PU damping). \url{https://www.agv-wheel.com/}
\bibitem{tzbot} TZBOT. \textit{AGV Drive Wheel — Suspension (differential)}.
\url{https://www.tzbotautomation.com/agv-drive-wheels/differential-drive-wheel/agv-drive-wheel-suspension.html}
\bibitem{dmk} BeUDMKE (dmkmotor). \textit{AGV Drive Wheel — shock-absorbing drive wheel}.
\url{https://www.dmkmotor.com/agv-drive-wheel/}
\bibitem{ezwheel} ez-Wheel. \textit{SWD\,125 Safety Wheel Drive} (24\,V, SIL2/PLd, for AGV/AMR), via
RobotShop. \url{https://www.robotshop.com/products/swd-125-safety-wheel-drive-agv-amr}
\bibitem{rokit} Bosch Rexroth. \textit{ROKIT Motor — all-in-one wheel drive for AMRs}.
\url{https://www.boschrexroth.com/}
\bibitem{ieee} IEEE/IROS. \textit{Flexible (multilayered) suspension mechanism for a differential-drive
mobile robot} (passive spring+damper, self-levelling; for tall, tip-prone robots).
\end{thebibliography}

\end{document}

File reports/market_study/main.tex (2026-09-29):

% !TEX program = latexmk
\documentclass[12pt,a4paper]{report}

\usepackage[utf8]{inputenc}
\usepackage{graphicx}
\usepackage{booktabs}
\usepackage{longtable} 
\usepackage{array}
\usepackage{hyperref}
\usepackage{geometry}
\usepackage{colortbl}
  \usepackage[table]{xcolor} 
\geometry{margin=2.5cm}
 
% Load project configuration 
\input{../../config/config.tex}

\title{Autonomous Modular Robot Market Study}
\author{\ProjectName~\TeamName}
\date{\today}     

\begin{document}

\hypersetup{pageanchor=false}
\begin{titlepage}   
    % Logo in top left corner 
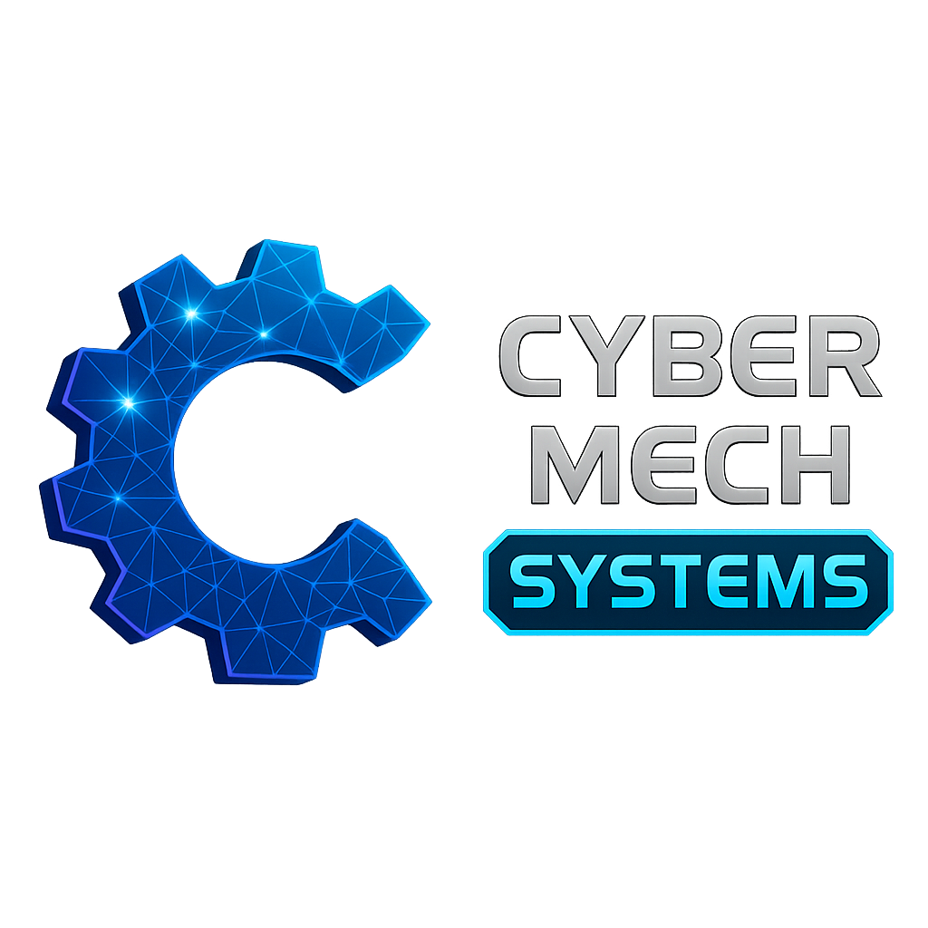
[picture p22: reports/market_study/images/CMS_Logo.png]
    
    
    \vspace{3cm}
    
    \begin{center}
        {\Large \textbf{Autonomous Modular Robot Market Study}} \\
        \vspace{1cm}
        {\large \ProjectFullName} \\
        \vspace{0.5cm}
        {\large \TeamName} \\
        \vspace{0.5cm}
        {\large \today}
    \end{center}
\end{titlepage}

\pagenumbering{roman}
\newpage

\input{sections/00_abbreviations}
\newpage

\tableofcontents
\clearpage
\pagenumbering{arabic}
\hypersetup{pageanchor=true} 
  
\input{sections/01_introduction}
\input{sections/02_sector_market_analysis_part1}
\input{sections/02_market_overview}
\input{sections/03_competitors}
\input{sections/04_target_clients}
\input{sections/05_pricing}
\input{sections/06_pain_points}
\input{sections/07_use_cases}
\input{sections/08_opportunities}
\input{sections/09_conclusion} 

\bibliographystyle{plain}
\bibliography{references}

\end{document}

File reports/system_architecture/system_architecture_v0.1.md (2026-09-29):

# AMR-X System Architecture v0.2

Maintained by: Manar Afli (Technical Project Manager / System Architect)
Status: Draft — updated after third week of team progress reports

This document is the single reference for how the mechanical, electrical,
software, and module-interface decisions fit together. It should be updated
as teams confirm or change values. Detailed values live in
`data/system_architecture/interfaces.csv` — do not duplicate numbers here,
reference the table.

**Related document:** `robotics/ARCHITECTURE.md` (added in PR #8 by Zeyneb)
covers the ROS 2 package-level implementation of the module software stack
in detail. This document stays at the system level and links out to it
rather than duplicating package contents — see Section 4.

## 1. Overview

AMR-X is a modular autonomous mobile robot. One base robot chassis accepts
interchangeable functional modules (inspection, secure cargo, handling,
robotic arm) through a shared docking interface. The base handles movement,
navigation, and power; the module handles the task-specific function. The
dual-arm module has been confirmed as the first module to be built (V1).

## 2. Mechanical Architecture

- Overall footprint: 800 mm x 600 mm x 420 mm (confirmed by Mechanical team)
- Drive: differential drive
- Wheels: 4 caster wheels (changed from 2 for stability and load
  distribution, relevant now that a heavier dual-arm module is planned)
- Module mounting zone: 500 mm x 400 mm, centered over the wheelbase
- A real CAD-exported URDF has been produced and integrated into
  simulation (see Section 4). Driving behavior and LiDAR output from the
  real model are still being validated.
- The dual-arm module is expected to require a center-of-gravity
  compensation of roughly 30-50 mm toward the rear (proposed, not yet
  validated in CAD)

Open item: internal component layout (battery, controller, wiring) is
still waiting on the Electrical team's final part list.

## 3. Electronics Architecture

- Battery: TBD, active research in progress
- Main computer / controller: TBD
- Motor drivers: TBD

Open item: none of these are selected yet. This remains the biggest
blocker for Mechanical's internal layout.

## 4. Software Architecture

- ROS 2 stack locked: **Ubuntu 24.04 + ROS 2 Jazzy + Gazebo Harmonic** as
  the default, with **Ubuntu 22.04 + ROS 2 Humble + Gazebo Fortress** kept
  as a supported compatibility path
- Full simulation loop is working end-to-end: the robot drives in a
  warehouse world with working teleoperation and LiDAR/IMU/odometry
  publishing correctly
- The real CAD-exported URDF is integrated and spawns correctly in Gazebo,
  replacing the earlier placeholder model. Still to confirm: driving
  behavior and `/scan` output from the real sensor configuration
- **Module software scaffold merged into main (PR #8):** 7 ROS 2 packages
  — `amr_interfaces`, `arm_description`, `arm_control`, `arm_moveit_config`,
  `module_manager`, `task_coordinator`, `dashboard_bridge`. This is an
  empty-but-buildable skeleton with real logic left as TODOs per package
  owner. Full detail in `robotics/ARCHITECTURE.md`. **Merged on 8 Jul
  without the frame-naming conflict below being resolved first.**
- Arm control will use **MoveIt2**, not Nav2, since the dual-arm module's
  job is manipulation rather than mobile navigation
- Dashboard communicates with ROS 2 over `rosbridge_server` and
  `roslibjs` via WebSocket; confirmed working for `/cmd_vel`, with
  `/odom` and `/imu` subscriptions planned next

## 5. Module Interface

- Connector: HARTING Han-Modular, carrying 24V power, CAN bus, and
  Ethernet
- Docking alignment: 12 mm diameter guide pins on a 450 x 350 mm pattern
- Docking locks: quarter-turn M8 locks, rated to 375 kg
- Docking detection: 2 inductive sensors, published to ROS topics
  `/module_docked` and `/module_id`
- Clearance zones defined so future modules cannot block the front LiDAR,
  emergency stop, or operator panel
- **Open conflict — module mount frame naming:** the mechanical/URDF side
  refers to the mount point as `module_interface_link`, while the new ROS
  package scaffold from PR #8 defines it as `module_mount_top`. These need
  to be reconciled to a single canonical name before more packages are
  built assuming either one. See Section 9.

## 6. Sensor Layout

- Proposed: dual LiDAR (front + rear) for 360-degree coverage and
  redundancy, proposed by Mechanical
- The currently integrated test URDF places a single LiDAR link at the
  front-top-centre position, matching CAD — this does not yet confirm
  whether the dual-LiDAR plan is still active or has been narrowed to one
- **Still not confirmed by Navigation/ROS team** — flagged as an open
  conflict, see Section 9

## 7. Navigation

- Nav2 configured, but currently using a placeholder footprint
- SLAM and AMCL localization tested successfully against the placeholder
  robot model; an EKF sensor-fusion config is currently being drafted
- Now that a real URDF is integrated, the footprint may be finalizable
  soon once the caster layout is locked

## 8. Power Distribution

TBD — depends entirely on Electrical team's battery and controller
selection, which is under active research. No layout can be finalized
until this is resolved.

## 9. Known Conflicts / Open Questions

This is the most important section of this document, keep it updated.

1. **[NEW, urgent — now live in main]** Module mount frame naming
   conflict: `module_interface_link` (mechanical/URDF) vs
   `module_mount_top` (merged via PR #8). This is no longer a
   before-it-happens risk — PR #8 was merged into `main` on 8 Jul without
   this being reconciled, so the mismatch is now sitting in the codebase.
   Needs an issue opened and a decision between the Module team and
   ROS/Sim team on which name is canonical, then a follow-up fix wherever
   the losing name was used.
2. Mechanical proposes 2 LiDARs; the currently integrated URDF only shows
   one LiDAR link. Needs explicit confirmation from Navigation/ROS on
   whether the dual-LiDAR plan is still active.
3. Navigation's footprint is still a placeholder; likely close to
   resolution now that the real URDF is integrated, pending final caster
   layout confirmation.
4. Electrical has not selected a battery or controller yet, which blocks
   Mechanical's internal layout.
5. **[NEW]** Two parallel architecture documents now exist — this
   document (system-level) and `robotics/ARCHITECTURE.md` (ROS
   package-level, from PR #8). Agreed approach: this document stays at
   the system/interface level and links to `ARCHITECTURE.md` for
   implementation detail, rather than the two documents duplicating each
   other. Confirm this approach with Zeyneb.

## 10. Future Modules

**Confirmed V1 module: dual-arm robotic arm module.** Mechanical is
researching hardware options (GrabCAD models); software has scaffolded
the arm packages (`arm_description`, `arm_control`, `arm_moveit_config`).

Candidate module research (from Chaima's market research, see
`Modules.pdf`):

- **Robotic arm:** Interbotix PincherX/WidowX (ROS-ready "arm + mobile
  base" kits, ~$2,000-6,500), Elephant Robotics myCobot 280/320
  (lightweight, ~$1,000-2,000, lower payload), uFactory xArm/Lite
  (higher payload up to 5kg, ~$3,300-10,000)
- **Shelf access:** Nord Modules Quick Mover/Pallet Lift (4-screw
  mounting, up to 1500kg), ROEQ Top Modules (MiR-compatible, built-in
  alignment/load sensors), Ocado Chuck (design reference only, not
  purchasable)
- **Inspection:** Clearpath Husky Observer (turnkey, ROS API, 10kg
  payload budget), or individually-assembled components (e-con Systems
  cameras, Orbbec depth sensors, thermal imaging modules) — likely the
  more realistic budget option

Not yet scoped: shelf-access and inspection modules remain future work
beyond the dual-arm V1.

---
*Change log*
- v0.1 — initial draft
- v0.2 — added dual-arm module confirmation, real URDF integration status,
  locked ROS stack decision, PR #8 module scaffold cross-reference, module
  mount frame naming conflict, precise docking hardware specs from
  Chaima's module research, dashboard communication method

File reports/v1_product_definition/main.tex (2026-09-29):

% !TEX program = latexmk
\documentclass[12pt,a4paper]{report}

\usepackage[utf8]{inputenc}
\usepackage{array}
\usepackage{booktabs}
\usepackage{geometry}
\usepackage{graphicx}
\usepackage{hyperref}
\usepackage{longtable}

\geometry{margin=2.5cm}
\hbadness=10000
\hfuzz=25pt

% Load project configuration generated from config/project_specs.json
\input{tables/generated/project_specs.tex}

\title{AMR-X V1 Product Definition Dossier}
\author{AMR-X Engineering Group}
\date{\today}

\begin{document}

\hypersetup{pageanchor=false}
\begin{titlepage}
    

    \vspace{3cm}

    \begin{center}
        {\Large \textbf{AMR-X V1 Product Definition Dossier}} \\
        \vspace{1cm}
        {\large \SpecProjectFullName} \\
        \vspace{0.5cm}
        {\large \SpecProjectTeam} \\
        \vspace{0.5cm}
        {\large \today}
    \end{center}
\end{titlepage}

\pagenumbering{roman}
\input{sections/00_abbreviations}
\newpage

\tableofcontents
\clearpage
\pagenumbering{arabic}
\hypersetup{pageanchor=true}

\input{sections/01_project_vision}
\input{sections/02_scope_and_versions}
\input{sections/03_global_specifications}
\input{sections/04_base_platform_definition}
\input{sections/05_module_interface}
\input{sections/06_requirements_matrix}
\input{sections/07_component_strategy}
\input{sections/08_base_bom}
\input{sections/modules/09_arm_module}
\input{sections/modules/10_shelf_access_module}
\input{sections/modules/11_secure_compartment_module}
\input{sections/modules/12_sensor_inspection_module}
\input{sections/13_build_buy_modify_custom}
\input{sections/14_verification_plan}
\input{sections/15_open_decisions}

\end{document}

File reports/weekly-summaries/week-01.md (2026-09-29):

## Weekly Summary: Progress Report

###  Achieved This Week

* **ROS 2 Workspace Organization:** Restructured the `robotics/` directory into 5 clean, distinct packages: `robot_description`, `simulation`, `control`, `navigation`, and `bringup`. The entire workspace now builds flawlessly using `colcon` on ROS 2 Humble + Ignition Gazebo Fortress.

#### ** Simulation, Mapping & Core Autonomy**
* **Full Simulation Integration:** The AMR-X platform now successfully spawns in the 3D warehouse world. Live telemetry pipelines are fully operational, with LiDAR (`/scan`), IMU (`/imu`), wheel odometry (`/odom`), and coordinate transforms (`/tf`) publishing reliably.
* **Navigation & SLAM Verification:** Integrated and merged navigation launch files (`slam.launch.py` and `nav2.launch.py`). Executed SLAM against the warehouse environment to map out a complete **15×16 m** grid, validating the entire sensor-to-TF chain end-to-end.
* **Teleoperation Ready:** Differential-drive teleoperation is live and stable, creating an established baseline for autonomous navigation demos.

#### **Mechanical Research & Drive-Wheel Suspension Study**
* **Mechanism Analysis:** Completed a comprehensive engineering review comparing candidate suspension mechanisms (sprung drive units vs. rocker systems) utilizing real-world robotics precedents.
* **Component Selection:** Shortlisted ready-to-buy suspension drive-wheel kits with target engineering specifications to preserve or improve upon in the upcoming design phase.
* **Report Compiled:** Assembled all research findings into a formalized report and successfully committed it to the repository.

---

###  Current Blockers & Team Coordination Notes

* **Incomplete URDF Model:** The current simulation URDF file only contains the robot base framework. 
  * *Resolution:*Simulation teams must coordinate with the mechanical team to acquire the complete CAD assembly exports to construct the finalized, multi-component URDF model.
* **System Environment Alignment Reminder:** 
  > ⚠️ **Note to Team:** The current ROS 2 stack is compiled for **Ubuntu 22.04 (Humble + Fortress)**. If anyone is testing or building on **Ubuntu 24.04 with Gazebo Harmonic** and encounters dependency or build conflicts, please open a GitHub Issue immediately so we can roll out a compatibility patch.

---

###  Objectives for Next Week:
still not defined

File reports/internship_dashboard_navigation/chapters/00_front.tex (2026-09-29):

% ---------------------------------------------------------------- page de garde
\begin{titlepage}
\thispagestyle{empty}
\begin{minipage}[c]{0.2\linewidth}
  \IfFileExists{figures/logo_insat.png}{}{}
\end{minipage}\hfill
\begin{minipage}[c]{0.58\linewidth}\centering
  {\bfseries RÉPUBLIQUE TUNISIENNE}\\[0.2em]
  Ministère de l'Enseignement Supérieur et de la Recherche Scientifique\\[0.2em]
  Université de Carthage\\[0.2em]
  Institut National des Sciences Appliquées et de Technologie
\end{minipage}\hfill
\begin{minipage}[c]{0.2\linewidth}
  \IfFileExists{figures/logo_carthage.png}{}{}
\end{minipage}

\vspace{0.8cm}
\noindent\rule{\linewidth}{0.5pt}
\begin{center}
  {\Huge Rapport de stage d'été}\\[0.4em]
  {\large Spécialité : Informatique Industrielle et Automatique}
\end{center}
\noindent\rule{\linewidth}{0.5pt}

\begin{center}
  {\LARGE\bfseries Supervision et commande web\\[0.2em]
  du robot autonome modulaire AMR-X}\\[0.6em]
  {\large Intégration du dashboard avec la navigation Nav2\\
  et validation en simulation ROS~2 / Gazebo}
\end{center}
\noindent\rule{\linewidth}{0.5pt}

\vspace{0.6cm}
\begin{center}
  {\bfseries Réalisé par :}\\[0.2em]
  {\LARGE Linda Ouaghlani}\\[1em]
  Organisme d'accueil : \textbf{CyberMech Systems} -- département R\&D / Robotique\\[0.3em]
  Projet : \emph{Design, Development, Simulation, and Validation\\
  of a Modular Autonomous Robotic System}
  \IfFileExists{figures/logo_cybermech.png}{\\[0.8em]}{}
\end{center}

\vspace{0.6cm}
\begin{center}
\begin{tabular}{|p{0.5\linewidth}|}
  \hline
  \centering\bfseries Encadrant(e) à CyberMech Systems \tabularnewline
  \centering\acompleter{Nom et prénom} \tabularnewline[2.2cm]
  \hline
\end{tabular}
\end{center}

\vfill
\begin{center}
  Période du stage : du 1\textsuperscript{er} juillet au 31 août 2026\\[0.4em]
  {\bfseries Année universitaire : 2025\,/\,2026}
\end{center}
\end{titlepage}

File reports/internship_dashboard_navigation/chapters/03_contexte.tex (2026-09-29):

\chapter{Présentation de l'entreprise et du projet}

\section*{Introduction}
Ce chapitre présente le cadre du stage. Il décrit d'abord l'entreprise d'accueil,
CyberMech Systems, puis son projet de robot autonome modulaire AMR-X et l'environnement
autonome construit autour de ce robot. Il précise ensuite la mission confiée à la
stagiaire, le cahier des charges, l'environnement de travail et la démarche suivie.

\section{Présentation de l'entreprise}
\textbf{CyberMech Systems} est une entreprise basée à Tunis dont le département
\textbf{R\&D / Robotique} conçoit et développe des systèmes robotiques autonomes. Le stage
s'est déroulé au sein de ce département, dans l'équipe chargée du projet AMR-X.

\acompleter{Compléter si besoin : date de création, domaines d'activité, organisation
de l'équipe.}

\section{Le projet AMR-X : un robot autonome modulaire}
AMR-X (\emph{Autonomous Modular Robot -- Extended}) est le robot mobile autonome
développé par CyberMech Systems. Son principe est la modularité : une \textbf{base
robotisée commune}, qui assure la mobilité, la perception et la navigation, reçoit des
\textbf{modules fonctionnels interchangeables} selon l'application visée, par exemple le
transport de charges en entrepôt ou la logistique en milieu hospitalier. Une même base
peut ainsi servir plusieurs usages sans être reconçue.

Le projet couvre l'ensemble du cycle de développement : définition du produit, étude de
marché, conception mécanique et électronique, logiciel robotique et outils de
supervision. La partie logicielle est développée sous ROS~2 Jazzy, avec le simulateur
Gazebo Harmonic, sur Ubuntu~24.04.

\section{Un environnement autonome autour du robot}
L'ambition de l'entreprise ne se limite pas au robot : elle construit un
\textbf{environnement autonome complet}, dans lequel le robot peut être simulé, se
localiser, naviguer seul et être supervisé par un opérateur. Cet environnement se compose
de quatre briques, représentées sur la figure~\ref{fig:environnement}.

\begin{figure}[htbp]
\centering
\begin{tikzpicture}[node distance=0.8cm and 0.9cm]
  \node[sim,minimum width=3.3cm,minimum height=1.6cm] (sim) {\textbf{Simulation}\\\scriptsize Gazebo Harmonic\\\scriptsize entrepôt, hôpital};
  \node[ros,right=of sim,minimum width=3.3cm,minimum height=1.6cm] (nav) {\textbf{Navigation}\\\scriptsize SLAM, AMCL\\\scriptsize Nav2};
  \node[web,right=of nav,minimum width=3.3cm,minimum height=1.6cm] (sup) {\textbf{Supervision}\\\scriptsize dashboard web\\\scriptsize flotte, missions};
  \node[bloc,fill=gray!10,below=1.1cm of nav,minimum width=6cm,minimum height=1.2cm] (robot)
    {\textbf{Robot AMR-X}\\\scriptsize base commune + modules interchangeables};
  \draw[fl] (robot) -- (sim);
  \draw[fl] (sim) -- node[lbl,above]{capteurs} (nav);
  \draw[fl,red!70!black,very thick] (nav) -- node[lbl,above,text=red!70!black]{stage} (sup);
  \draw[fl] (robot.north) -- (nav.south);
  \draw[fl] (robot) -| (sup);
\end{tikzpicture}
\caption{Environnement autonome du projet AMR-X ; en rouge, le lien réalisé pendant le stage.}
\label{fig:environnement}
\end{figure}

\subsection{Simulation}
Le robot AMR-X est modélisé et simulé dans Gazebo Harmonic, dans plusieurs mondes :
entrepôt et hôpital. Le monde utilisé pendant ce stage est l'entrepôt
\code{warehouse\_harmonic} (figure~\ref{fig:gazebo}, chapitre~\ref{chap:validation}). Le
robot simulé est équipé de deux LiDAR dont les mesures sont fusionnées, d'une caméra et
d'une centrale inertielle.

\subsection{Localisation et navigation}
La carte de l'environnement est produite par SLAM. Le robot s'y localise avec AMCL, et la
pile Nav2 planifie son trajet (planificateur global NavFn) et le suit en évitant les
obstacles (contrôleur local MPPI). Une destination est transmise à Nav2 par l'action
ROS~2 \code{/navigate\_to\_pose}.

\subsection{Supervision}
Le dashboard web est l'interface de l'opérateur. Il comprend :
\begin{itemize}
  \item un \textbf{frontend} React organisé en pages : vue d'ensemble, robots, missions,
    carte en direct (\emph{Live map}), alertes, modules, téléopération, paramètres et
    gestion des utilisateurs ;
  \item un \textbf{backend} FastAPI qui gère les comptes (avec approbation par un
    administrateur), les robots, les missions et les alertes dans une base de données.
\end{itemize}
La page \emph{Live map} affiche le monde simulé sous forme de plan 2D ou de vue 3D,
à partir des fichiers de description SDF des mondes Gazebo.

\section{Mission du stage}

\subsection{Besoin}
Au début du stage, la simulation, la navigation et le dashboard existaient mais
n'étaient pas encore reliés. Le dashboard affichait le plan du monde, mais pas la position
réelle du robot simulé, et il ne permettait pas de lui envoyer une destination. La
commande de la navigation se faisait uniquement depuis les outils ROS (RViz).

La mission de la stagiaire est de construire ce lien : \emph{permettre à un opérateur de
commander la navigation du robot AMR-X depuis le dashboard, en lui garantissant que la
position et l'état affichés correspondent réellement à ceux du robot}.

Cela implique de faire communiquer le navigateur, qui utilise des WebSockets, avec
ROS~2 ; de garantir qu'une commande n'est ni perdue ni exécutée deux fois ; d'exprimer la
position du robot dans le même repère que le plan affiché ; et de signaler clairement à
l'opérateur lorsque les données ne sont plus fiables.

\subsection{Cahier des charges}
Le tableau~\ref{tab:besoins} résume les besoins fonctionnels.

\begin{table}[htbp]
\centering\small
\begin{tabularx}{\linewidth}{@{}lX@{}}
\toprule
\textbf{Réf.} & \textbf{Besoin} \\
\midrule
BF1 & Afficher en direct la position et l'orientation du robot sur la \emph{Live map} (vues 2D et 3D). \\
BF2 & Choisir une destination par clic sur la carte 2D ou par saisie de X, Y (m) et du cap (°). \\
BF3 & Envoyer la destination à Nav2 et obtenir un acquittement explicite de la demande. \\
BF4 & Suivre l'état de la navigation : envoi, navigation, distance restante, résultat final. \\
BF5 & Annuler la navigation en cours et afficher la confirmation d'annulation. \\
BF6 & Refuser les destinations invalides (hors carte, occupées, non finies, mauvais monde) avec un message explicite. \\
\bottomrule
\end{tabularx}
\caption{Besoins fonctionnels.}
\label{tab:besoins}
\end{table}

Les besoins non fonctionnels sont les suivants :
\begin{itemize}
  \item \textbf{Fidélité} : ne jamais afficher de position ou de résultat inventé ; le
    succès provient uniquement du résultat de Nav2.
  \item \textbf{Sûreté des commandes} : un seul but actif à la fois et aucun renvoi
    automatique d'une commande dont le résultat est incertain.
  \item \textbf{Fraîcheur des données} : bloquer les commandes si l'état n'a pas été reçu
    depuis 2,5~s.
  \item \textbf{Intégration} : s'appuyer sur le dashboard, Nav2 et la simulation du projet
    et conserver l'authentification existante.
  \item \textbf{Reproductibilité} : pouvoir lancer tout l'environnement par une commande
    documentée.
\end{itemize}

\subsection{Périmètre}
Le travail porte sur un robot, un serveur de navigation et un monde actif à la fois, en
simulation. Pour éviter toute commande d'un robot physique, la passerelle refuse les
destinations lorsque le temps simulé n'est pas utilisé. La pause et la reprise d'une
navigation, l'arbitrage entre plusieurs sources de commande et l'authentification au
niveau de rosbridge ne font pas partie du périmètre.

\section{Environnement de travail}
Le tableau~\ref{tab:env} présente les outils utilisés.

\begin{table}[htbp]
\centering\small
\begin{tabular}{@{}ll@{}}
\toprule
\textbf{Élément} & \textbf{Version / outil} \\
\midrule
Système d'exploitation & Ubuntu 24.04 \\
Intergiciel robotique & ROS~2 Jazzy \\
Simulateur & Gazebo Harmonic \\
Navigation & Nav2 (AMCL, NavFn, MPPI) \\
Pont web & rosbridge\_server 2.7.1 (WebSocket, port 9090) \\
Frontend & React 19, Vite 8, roslib 2.1 \\
Backend & FastAPI, SQLAlchemy, Alembic \\
Environnement JavaScript & Node.js 20 \\
Gestion de version & Git, GitHub \\
\bottomrule
\end{tabular}
\caption{Environnement logiciel du stage.}
\label{tab:env}
\end{table}

\section{Démarche}
Le travail a été conduit en quatre étapes :
\begin{enumerate}
  \item prise en main du projet : simulation, configuration de Nav2 et dashboard ;
  \item conception du protocole entre le navigateur et Nav2 et de la gestion des repères ;
  \item développement de la passerelle ROS~2 et des composants du dashboard, avec des tests
    unitaires ;
  \item intégration de l'ensemble et validation par des essais mesurés dans Gazebo.
\end{enumerate}

\section*{Conclusion}
Ce chapitre a présenté CyberMech Systems, son robot autonome modulaire AMR-X et
l'environnement autonome construit autour de lui. La mission du stage consiste à relier
la supervision web à la navigation du robot. Le chapitre suivant décrit la conception
retenue.

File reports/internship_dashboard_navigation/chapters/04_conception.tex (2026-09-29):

\chapter{Conception de la solution}
\label{chap:conception}

\section*{Introduction}
Ce chapitre présente la conception retenue pour relier le dashboard à Nav2. Il décrit
l'architecture générale, justifie le choix d'une passerelle ROS~2 dédiée, puis détaille le
protocole de communication, la machine d'états d'une demande de navigation, la gestion
des repères et les règles de sûreté.

\section{Architecture générale}
La figure~\ref{fig:architecture} présente la chaîne retenue. Le navigateur communique avec
ROS~2 par rosbridge, au moyen d'une connexion WebSocket. Il n'appelle pas Nav2
directement : toutes les commandes passent par un nœud intermédiaire,
\code{dashboard\_navigation}, qui vérifie la demande, dialogue avec Nav2 par l'action
\code{/navigate\_to\_pose} et publie en retour un état synthétique. La position du robot
est lue dans l'arbre TF (transformation \code{map}~$\rightarrow$~\code{base\_link}), qui
combine la localisation AMCL et l'odométrie.

\begin{figure}[htbp]
\centering
\resizebox{\linewidth}{!}{%
\begin{tikzpicture}[node distance=0.9cm and 1.1cm]
  \node[web,minimum width=3.4cm] (ui) {Live Map (React)\\\scriptsize NavigationPanel\\\scriptsize useNavigation};
  \node[ros,right=1.6cm of ui,minimum width=2.6cm] (rb) {rosbridge\\\scriptsize WebSocket :9090};
  \node[neuf,right=1.6cm of rb,minimum width=3.4cm] (gw) {Passerelle\\\code{dashboard\_navigation}};
  \node[ros,right=1.6cm of gw,minimum width=2.6cm] (nav) {Nav2\\\scriptsize bt\_navigator};
  \node[sim,below=1.5cm of nav,minimum width=2.6cm] (gz) {Gazebo\\\scriptsize robot simulé};
  \node[ros,below=1.5cm of gw,minimum width=3.4cm] (tf) {TF \code{map}$\rightarrow$\code{base\_link}\\\scriptsize + costmap globale};
  \node[web,below=1.5cm of ui,minimum width=3.4cm,fill=gray!10] (api) {Backend FastAPI\\\scriptsize comptes, flotte};
  \draw[fl] ([yshift=2mm]ui.east) -- node[lbl,above=1pt]{services} ([yshift=2mm]rb.west);
  \draw[fl] ([yshift=-2mm]rb.west) -- node[lbl,below=1pt]{état JSON} ([yshift=-2mm]ui.east);
  \draw[fl] ([yshift=2mm]rb.east) -- node[lbl,above=1pt]{submit / cancel} ([yshift=2mm]gw.west);
  \draw[fl] ([yshift=-2mm]gw.west) -- node[lbl,below=1pt]{4 Hz} ([yshift=-2mm]rb.east);
  \draw[fl] ([yshift=2mm]gw.east) -- node[lbl,above=1pt]{action} ([yshift=2mm]nav.west);
  \draw[fl] ([yshift=-2mm]nav.west) -- node[lbl,below=1pt]{retour} ([yshift=-2mm]gw.east);
  \draw[fl] (nav) -- node[lbl]{\code{cmd\_vel}} (gz);
  \draw[fl] (gz) -- node[lbl]{capteurs, AMCL} (tf);
  \draw[fl] (tf) -- node[lbl]{pose, coûts} (gw);
  \draw[fl] (ui) -- node[lbl]{HTTP REST} (api);
\end{tikzpicture}}
\caption{Architecture de la chaîne de commande et de retour (en rouge, le nœud développé).}
\label{fig:architecture}
\end{figure}

\section{Choix d'une passerelle dédiée}
Deux approches étaient possibles pour envoyer une destination depuis le navigateur :
publier directement un message sur le topic \code{/goal\_pose} ou appeler l'action Nav2
depuis le navigateur, ou bien passer par un nœud intermédiaire. La première approche est
simple mais ne fournit aucun accusé de réception : le navigateur ne sait pas si la commande
a été reçue, refusée ou perdue. La seconde place dans le navigateur toute la logique de
vérification, qui peut alors être contournée ou dupliquée par plusieurs onglets.

La passerelle dédiée a été retenue pour les raisons suivantes :
\begin{itemize}
  \item chaque commande reçoit une réponse explicite (\emph{acceptée} ou \emph{refusée}
    avec un motif) ;
  \item les vérifications (monde, coordonnées, carte, disponibilité de Nav2) sont faites
    côté ROS, au plus près des données ;
  \item un seul but peut être actif à la fois, quel que soit le nombre de navigateurs ;
  \item l'état publié est unique et partagé : tous les clients voient la même information.
\end{itemize}

\section{Protocole de communication}

\subsection{Service de soumission}
La soumission utilise une interface de service dédiée, définie dans le paquet
\code{navigation\_msgs} :
\begin{lstlisting}
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

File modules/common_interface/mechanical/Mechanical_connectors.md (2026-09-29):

Mechanical connectors:

Use a **bolted flange** for permanent or rarely-changed mounts such as the base-to-arm joint, since it offers maximum rigidity and handles high torque and moment loads but is not quick-swap.

Use a **kinematic mount** with dowel pins and a clamp or collar wherever precise, repeatable alignment is needed after re-docking, such as arm-to-base connections where joint calibration must stay valid. Use a dovetail with a locking pin for moderate-frequency swaps with decent lateral rigidity, suited to lighter modules like sensors or small tools.

Use a **bayonet** or **twist-lock connector** for fast, tool-less swaps where torsional load is low, such as sensor heads or light end-effectors.

Use a **quick-change ball-lock** or **pneumatic coupler** for high-frequency tool-changing at the wrist, such as swapping grippers mid-task, since these are fast and robust and commonly used in industrial tool-changers.

Use a **magnetic dock** only for very light modules with low load requiring extremely fast attachment without a latch, since it is weak against torque and unsuitable for a full arm.

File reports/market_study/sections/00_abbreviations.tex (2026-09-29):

\chapter*{Abbreviations and Acronyms}
\addcontentsline{toc}{chapter}{Abbreviations and Acronyms}

\begin{longtable}{>{\raggedright\arraybackslash}p{0.22\textwidth}>{\raggedright\arraybackslash}p{0.68\textwidth}}
\toprule
\textbf{Abbreviation} & \textbf{Meaning} \\
\midrule
\endhead
A / S / C / N & The four platform modules -- Arm (A), Shelf-access (S), Compartment (C), and Sensors (N) \\
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

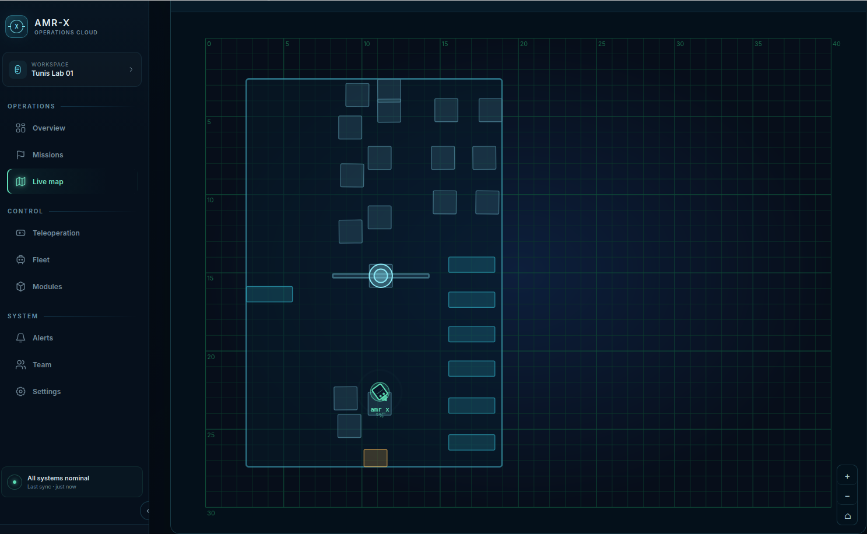
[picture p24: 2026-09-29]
reports/internship_dashboard_navigation/figures/live_map_navigation.png

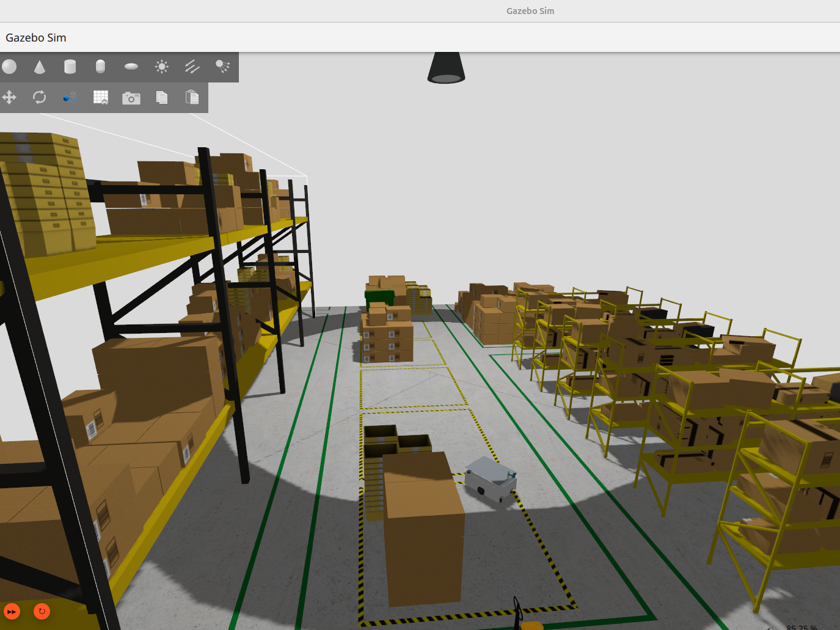
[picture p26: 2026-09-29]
reports/internship_dashboard_navigation/figures/gazebo_warehouse.png

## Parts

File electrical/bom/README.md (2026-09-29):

# Bill of Materials

Component list and specifications.

## Purpose

Track and document all electrical components for procurement and assembly.

## Format

Store BOM as structured tables or spreadsheets including:

- Component name and description
- Manufacturer and part number
- Quantity required
- Unit cost (when finalized)
- Supplier
- Specifications and notes

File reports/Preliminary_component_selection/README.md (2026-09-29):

# Electrical Component Selection Report

This report documents the selected electrical, computing, sensing, safety, power, and motion components for the AMR Prototype V1.
Below is an overview of the components selected based on the latest approved requirements. Details of each one are available in the full report.

## Summary: Component Selection Overview

| # | Component | Qty | Selected Model | Cost (TND) | Lead |
|---|---|-----|---|---|---|
| **COMPUTING UNIT** ||||| |
| 1 | Main Computer | 1 | NVIDIA Jetson Orin Nano | 1500--2000 | 2--4w |
| 2 | Microcontroller | 1 | STM32 Nucleo-F446RE | 90--130 | 1w |
| **SENSORS** ||||| |
| 3 | LiDAR Scanner | 1 | RPLIDAR A2M12 | 1200--1600 | 1w |
| 4 | Depth Camera | 1 | Intel RealSense D435i | 2000--3000 | 2w |
| 5 | IMU (9-axis) | 1 | BNO055 | 100--120 | 1--2w |
| 6 | RGB Camera | 1 | Logitech C920 HD Pro | 500 | <1w |
| 7 | Proximity Sensors | 4 | Industrial Ultrasonic M18 | 20--50 each | 1w |
| 8 | Wheel Encoders | 2 | Omron E6B2-CWZ6C (optional) | 500--700 each | 1--2w |
| **SAFETY SYSTEM** ||||| |
| 9 | Emergency Stop | 1 | Schneider XB2-BS542 | 10--20 | <1w |
| 10 | Safety Relay | 1 | Pilz PNOZ X2.8P | 600--900 | 2--3w |
| 11 | Warning Beacon | 1 | AD22-22MSD LED+Alarm | 10 | <1w |
| **POWER SYSTEM** ||||| |
| 12 | Battery Pack | 1 | LiFePO4 24 V 20 Ah (UPGRADED) | 1800--2200 | 2--4w |
| 13 | Main Fuse (80 A) | 1 | ANL 80 A + holder | 50 | <1w |
| 14 | Motor Fuse (30 A) | 1 | ANL 30 A | 20 | <1w |
| 15 | Compute Regulator | 1 | XL4005 buck conv. (24 → 12 V) | 80--120 | <1w |
| 16 | Sensor Regulator | 1 | HLK-5M05 buck conv. (24 → 5 V) | 100--150 | <1w |
| 17 | Wiring/Connectors | --- | 4/6/8/10 AWG + XT90 | 200--250 | <1w |
| 18 | Capacitors/EMI | --- | 100 μF × 3 + ferrite clamps | 50 | <1w |
| **MOTION SYSTEM (UPDATED)** ||||| |
| 19 | Drive Motor (EC45) | 2 | Maxon EC 45 Flat 70 W @ 24 V | 700--900 each | 2--4w |
| 20 | Planetary Gearbox | 2 | Maxon GP 42C 33:1 | 900--1200 each | 2--4w |
| 21 | Flexible Couplings | 2 | Oldham or jaw type | 160--200 each | 1--2w |
| 22 | Motor Driver | 1 | Pololu VNH5019 dual | 220--300 | 1--3w |
| 23 | Drive Wheels | 2 | 180 mm solid rubber | 60--120 each | 1--2w |
| 24 | Caster Wheels | 2 | ROUE PIVOTANTE FREIN LISS 80 AVO | 26 each | 1--2w |

### Total Estimated Cost

**11200--18000 TND**

## Full Report

Build from the repository root:

```bash
bash tools/build_reports.sh
```

Generated PDF:

```text
build/Preliminary_component_selection/Preliminary_component_selection.pdf
```

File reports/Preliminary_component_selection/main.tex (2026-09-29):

\documentclass[12pt,a4paper]{article}

\usepackage[utf8]{inputenc}
\usepackage[T1]{fontenc}
\usepackage{geometry}
\usepackage{graphicx}
\usepackage{float}
\usepackage{longtable}
\usepackage{array}
\usepackage{hyperref}
\usepackage{enumitem}
\usepackage{booktabs}
\usepackage{titlesec}
\usepackage{amsmath}
\usepackage{amssymb}

\geometry{margin=2.5cm}

\title{
\textbf{Component Selection Report}\\
Modular Warehouse AMR Prototype V1}

\begin{document}

\maketitle

\section{Design Requirements Summary}

\begin{itemize}
\item Base dimensions: $800 \times 600 \times 420$ mm 
\item Ground clearance: 40 mm 
\item Drive architecture: differential drive 
\item Drive wheels: 2 centrally positioned wheels 
\item Initial wheel diameter: 180 mm 
\item Passive support: 2 caster wheels 
\item Initial caster diameter: 100 mm 
\item Initial module interface area: $500 \times 400$ mm 
\item Module interface position: centred on the upper platform 
\item Electrical baseline: 24 V 
\item Normal speed: 0.8 to 1.2 m/s 
\item Maximum design speed: 1.5 m/s
\end{itemize}

\newpage
%%%%%%%%%%%%%%%%%%%%%%%%%%%%%%%%%%%%%%%%%%%%%%%%%%%%%%%
\section{Computing unit}
\subsection{ Main Computer}
\begin{longtable}{|p{4cm}|p{10cm}|}
\hline
\textbf{Parameter} & \textbf{Details} \\
\hline

Component &
NVIDIA Jetson Orin Nano Developer Kit \\
\hline

Function &
Provides the onboard computing platform responsible for autonomous navigation, sensor fusion, SLAM, obstacle detection, teleoperation, and future AI applications. \\
\hline

Alternative Options &
Raspberry Pi 5 (8 GB)
\\
\hline

Technical Specifications &
\begin{itemize}
\item CPU: 6-core Arm Cortex-A78AE
\item GPU: 1024-core NVIDIA Ampere
\item AI Performance: Up to 40 TOPS
\item RAM: 8 GB LPDDR5
\item Storage: microSD / NVMe SSD
\item Ethernet: Gigabit
\item USB 3.2 Ports: 4
\item Power Consumption: 7--15 W
\item Quantity Required: 1
\end{itemize}
\\
\hline

Procurement &
Buy \\
\hline

Price &
Approximately 1500--2000 TND. \\
\hline

Supplier / Link &
\begin{itemize}
\item 2B TRADING
\item DigiKey
\item NVIDIA Authorized Resellers
\end{itemize}
\\
\hline

Availability &
Imported; moderate delivery time. \\
\hline

Delivery Difficulty &
Medium \\
\hline

Compatibility &
Fully compatible with Ubuntu 22.04, ROS2 Humble, Nav2, SLAM Toolbox, Intel RealSense cameras, and RPLIDAR sensors. \\
\hline

Software Support &
Official NVIDIA JetPack SDK, CUDA, TensorRT, ROS2 packages. \\
\hline

Risks &
\begin{itemize}
\item Higher cost than Raspberry Pi.
\item Requires active cooling.
\item Availability may fluctuate.
\end{itemize}
\\
\hline

Final Recommendation &
Recommended because it provides enough computational power for navigation, perception, and future AI modules while remaining compact and energy efficient. \\
\hline

\end{longtable}

%%%%%%%%%%%%%%%%%%%%%%%%%%%%%%%%%%%%%%%%%%%%%%%%%%%%%%%
\subsection{Microcontroller}

\begin{longtable}{|p{4cm}|p{10cm}|}
\hline
\textbf{Parameter} & \textbf{Details} \\
\hline

Component &
STM32 Nucleo-F446RE Development Board \\
\hline

Function &
Handles low-level control tasks such as motor control, encoder acquisition, sensor interfacing, and communication with the onboard computer. \\
\hline

Alternative Options &
\begin{itemize}
\item ESP32 DevKit
\item Arduino Mega 2560
\end{itemize}
\\
\hline

Technical Specifications &
\begin{itemize}
\item CPU: ARM Cortex-M4
\item Clock Frequency: 180 MHz
\item Flash Memory: 512 KB
\item SRAM: 128 KB
\item Interfaces: UART, SPI, I2C, CAN, USB
\item Operating Voltage: 3.3 V
\item Quantity Required: 1
\end{itemize}
\\
\hline

Procurement &
Buy \\
\hline

Price &
Approximately 90--130 TND. \\
\hline

Supplier / Link &
\begin{itemize}
\item RS Components 
\item Soulilah Electronics
\item 2B TRADING
\end{itemize}
\\
\hline

Availability &
Widely available internationally. \\
\hline

Delivery Difficulty &
Low \\
\hline

Compatibility &
Fully compatible with ROS2 through micro-ROS and serial communication interfaces. \\
\hline

Software Support &
STM32CubeIDE, FreeRTOS, micro-ROS. \\
\hline

Risks &
Requires proper firmware design. \\
\hline

Final Recommendation &
Recommended because it provides industrial reliability, real-time capabilities, and excellent peripheral support. \\
\hline

\end{longtable}

%%%%%%%%%%%%%%%%%%%%%%%%%%%%%%%%%%%%%%%%%%%%%%%%%%%%%%%
\section{Sensors}
\subsection{LiDAR}

\begin{longtable}{|p{4cm}|p{10cm}|}
\hline
\textbf{Parameter} & \textbf{Details} \\
\hline

Component &
RPLIDAR A2M12 Laser Scanner \\
\hline

Function &
Provides environmental mapping, localization, and obstacle detection. \\
\hline

Alternative Options &
\begin{itemize}
\item RPLIDAR A3
\item Hokuyo UST-10LX
\end{itemize}
\\
\hline

Technical Specifications &
\begin{itemize}
\item Range: Up to 12 m
\item Scan Frequency: 5--15 Hz
\item Angular Resolution: $0.225°$ to $0.45°$
\item Interface: USB
\item Power Consumption: Under 3 W
\item Quantity Required: 1
\end{itemize}
\\
\hline

Procurement &
Buy \\
\hline

Price &
Approximately 1200--1600 TND. \\
\hline

Supplier &
2B TRADING, Didactico. \\
\hline

Availability &
Generally available. \\
\hline

Delivery Difficulty &
Low \\
\hline

Compatibility &
Fully compatible with ROS2 and SLAM Toolbox. \\
\hline

Software Support &
Official ROS drivers available. \\
\hline

Risks &
\begin{itemize}
\item Sensitive to direct sunlight.
\item Performance decreases on transparent surfaces.
\end{itemize}
\\
\hline

Final Recommendation &
Recommended because it provides sufficient range and accuracy for indoor warehouse navigation at a reasonable cost. \\
\hline

\end{longtable}

%%%%%%%%%%%%%%%%%%%%%%%%%%%%%%%%%%%%%%%%%%%%%%%%%%%%%%%
\subsection{Depth Camera}

\begin{longtable}{|p{4cm}|p{10cm}|}
\hline
\textbf{Parameter} & \textbf{Details} \\
\hline

Component &
Intel RealSense D435i \\
\hline

Function &
Provides near-field obstacle detection and 3D perception. \\
\hline

Alternative Options &
\begin{itemize}
\item Intel RealSense D455
\item Orbbec Astra
\end{itemize}
\\
\hline

Technical Specifications &
\begin{itemize}
\item Depth Range: 0.11--10 m
\item RGB Resolution: $1920 \times 1080$
\item Stereo Cameras: Yes
\item IMU: Integrated
\item Interface: USB 3.0
\item Quantity Required: 1
\end{itemize}
\\
\hline

Procurement &
Buy \\
\hline

Price &
Approximately 2000--3000 TND. \\
\hline

Supplier &
Didactico, UBuy tunisia. \\
\hline

Availability &
Usually available on order. \\
\hline

Delivery Difficulty &
Medium \\
\hline

Compatibility &
Fully compatible with ROS2. \\
\hline

Software Support &
Intel RealSense SDK and ROS drivers. \\
\hline

Risks &
\begin{itemize}
\item High depth noise/error at distances exceeding 3 meters.
\item Sensitive to direct sunlight.
\end{itemize}
\\
\hline

Final Recommendation &
Recommended because it significantly improves obstacle detection and future computer vision applications. \\
\hline

\end{longtable}

%%%%%%%%%%%%%%%%%%%%%%%%%%%%%%%%%%%%%%%%%%%%%%%%%%%%%%%
\subsection{IMU}

\begin{longtable}{|p{4cm}|p{10cm}|}
\hline
\textbf{Parameter} & \textbf{Details} \\
\hline

Component &
BNO055 9-Axis IMU \\
\hline

Function &
Measures acceleration, angular velocity, and orientation for sensor fusion and localization. \\
\hline

Alternative Options &
\begin{itemize}
\item MPU9250
\item ICM20948
\end{itemize}
\\
\hline

Technical Specifications &
\begin{itemize}
\item 3-axis Accelerometer
\item 3-axis Gyroscope
\item 3-axis Magnetometer
\item Integrated Sensor Fusion
\item Interfaces: I2C, UART
\item Quantity Required: 1
\end{itemize}
\\
\hline

Procurement &
Buy \\
\hline

Price &
Approximately 100--120 TND. \\
\hline

Supplier &
UBuy tunisia. \\
\hline

Availability &
Usually available on order. \\
\hline

Delivery Difficulty &
Medium to High \\
\hline

Compatibility &
Fully compatible with ROS2 IMU packages. \\
\hline

Final Recommendation &
Recommended because its onboard sensor fusion greatly simplifies localization implementation. \\
\hline

\end{longtable}

%%%%%%%%%%%%%%%%%%%%%%%%%%%%%%%%%%%%%%%%%%%%%%%%%%%%%%%
\section{Proximity Sensor}

\begin{longtable}{|p{4cm}|p{10cm}|}
\hline
\textbf{Parameter} & \textbf{Details} \\
\hline

Component &
Industrial Ultrasonic Sensor M18 \\
\hline

Function &
Provides near-field and low-height obstacle detection that complements the LiDAR. \\
\hline

Alternative Options &
\begin{itemize}
\item HC-SR04
\item Sharp GP2Y0A21
\end{itemize}
\\
\hline

Technical Specifications &
\begin{itemize}
\item Range: 20 cm--4 m
\item Response Time: $<$50 ms
\item Supply Voltage: 12--24 V
\item Protection Rating: IP67
\item Quantity Required: 4
\end{itemize}
\\
\hline

Procurement &
Buy \\
\hline

Price &
Approximately 20--50 TND each. \\
\hline

Supplier &
CoThings, 2B TRADING. \\
\hline

Availability &
Usually available. \\
\hline

Delivery Difficulty &
Low to Medium \\
\hline

Final Recommendation &
Recommended because it can detect low obstacles that may not be visible to the LiDAR. \\
\hline

\end{longtable}

%%%%%%%%%%%%%%%%%%%%%%%%%%%%%%%%%%%%%%%%%%%%%%%%%%%%%%%
\subsection{RGB Camera}

\begin{longtable}{|p{4cm}|p{10cm}|}
\hline
\textbf{Parameter} & \textbf{Details} \\
\hline

Component &
Logitech C920 HD Pro Webcam \\
\hline

Function &
Provides RGB image acquisition for monitoring, computer vision applications, object detection, QR code recognition, and future AI modules. Although not strictly required for Version 1 navigation, an RGB camera significantly improves the extensibility of the platform. \\
\hline

Alternative Options &
\begin{itemize}
\item Raspberry Pi Camera Module 3
\item Intel RealSense RGB Camera (integrated with D455)
\end{itemize}
\\
\hline

Technical Specifications &
\begin{itemize}
\item Resolution: $1920 \times 1080$ pixels (1080p)
\item Frame Rate: 30 fps
\item Field of View: $78°$
\item Interface: USB 2.0
\item Autofocus: Yes
\item Integrated Microphones: Yes
\item Power Consumption: Approximately 2 W
\item Quantity Required: 1
\end{itemize}
\\
\hline

Procurement &
Buy \\
\hline

Price &
Approximately 500 TND. \\
\hline

Supplier / Link &
\begin{itemize}
\item MyTek Tunisia
\item Tunisianet
\end{itemize}
\\
\hline

Delivery Difficulty &
Very Low \\
\hline

Compatibility &
Fully compatible with Ubuntu 22.04, ROS2, OpenCV, and AI frameworks such as TensorFlow and PyTorch. \\
\hline

Software Support &
Official Linux UVC drivers, OpenCV support, ROS2 usb\_cam package. \\
\hline

Risks &
\begin{itemize}
\item Limited depth perception.
\item Performance depends on lighting conditions.
\item Not suitable as the sole navigation sensor.
\end{itemize}
\\
\hline

Final Recommendation &
Recommended because it is inexpensive, reliable, easy to integrate with ROS2, and provides a solid foundation for future computer vision applications while keeping the cost of the prototype low.
\\
\hline

\end{longtable}

%%%%%%%%%%%%%%%%%%%%%%%%%%%%%%%%%%%%%%%%%%%%%%%%%%%%%%%
\section{Wheel Encoder}
Only necessary when drive motors don't come with integrated encoders.

\begin{longtable}{|p{4cm}|p{10cm}|}
\hline
\textbf{Parameter} & \textbf{Details} \\
\hline

Component &
Omron E6B2-CWZ6C Incremental Rotary Encoder \\
\hline

Function &
Measures wheel rotational speed and displacement to estimate the robot's position and velocity. Wheel encoder data are essential for odometry, localization, and sensor fusion with the IMU and LiDAR.\\
\hline

Alternative Options &
\begin{itemize}
\item Generic 600 PPR Incremental Encoder
\item CUI AMT102-V Modular Encoder
\end{itemize}
\\
\hline

Technical Specifications &
\begin{itemize}
\item Encoder Type: Incremental
\item Resolution: 600 Pulses per Revolution (PPR)
\item Output Channels: A, B, Z
\item Supply Voltage: 5--24 V
\item Maximum Rotation Speed: 6000 rpm
\item Protection Rating: IP50
\item Quantity Required: 2
\end{itemize}
\\
\hline

Procurement &
Buy \\
\hline

Price &
Approximately 500--700 TND per encoder. \\
\hline

Supplier / Link &
\begin{itemize}
\item UBuy Tunisia
\item Schneider and Omron distributors in Tunisia

\end{itemize}
\\
\hline

Availability &
Usually available on order. \\
\hline

Delivery Difficulty &
Medium to High \\
\hline

Compatibility &
Fully compatible with STM32 timer peripherals, ROS2 Control, and differential-drive odometry packages. \\
\hline

Software Support &
Supported by STM32 HAL libraries, micro-ROS, and ROS2 diff\_drive\_controller packages. \\
\hline

Risks &
\begin{itemize}
\item Mechanical misalignment can reduce accuracy.
\item Wheel slippage introduces odometry errors.
\item Dust and vibration may affect long-term performance.
\end{itemize}
\\
\hline

Final Recommendation &
Recommended because it offers industrial reliability, sufficient resolution for indoor navigation, and straightforward integration with ROS2 localization and SLAM algorithms.
\\
\hline

\end{longtable}
%%%%%%%%%%%%%%%%%%%%%%%%%%%%%%%%%%%%%%%%%%%%%%%%
\section{Safety}
\subsection{Emergency stop system}

\begin{longtable}{|p{4cm}|p{10cm}|}
\hline
\textbf{Parameter} & \textbf{Details} \\
\hline

Component &
Schneider Electric XB2-BS542 Emergency Stop Push Button \\
\hline

Function &
Provides an immediate and reliable method to safely stop the robot in emergency situations by cutting power to the drive system and placing the robot in a safe state. \\
\hline

Alternative Options &
\begin{itemize}
\item Omron A22E Emergency Stop Push Button
\item Generic Industrial Emergency Stop Button
\end{itemize}
\\
\hline

Technical Specifications &
\begin{itemize}
\item Mushroom Head Diameter: 40 mm
\item Contact Configuration: 1 NC + 1 NO
\item Mechanical Life: $>$100,000 operations
\item Mounting Diameter: 22 mm
\item Degree of Protection: IP65
\item Compliance: IEC 60947-5-5
\item Quantity Required: 1 
\end{itemize}
\\
\hline

Procurement &
Buy \\
\hline

Price &
Approximately 10--20 TND \\
\hline

Supplier / Link &
\begin{itemize}
\item Seli tn
\item Schneider Electric Tunisia

\end{itemize}
\\
\hline

Availability &
Generally available locally. \\
\hline

Delivery Difficulty &
Low \\
\hline

Compatibility &
Compatible with all motor drivers and safety relay architectures. \\
\hline

Software Support &
No software required. The E-stop should be implemented as a hardware safety mechanism independent of software. \\
\hline

Risks &
\begin{itemize}
\item Incorrect wiring may prevent proper shutdown.
\item Inadequate placement may reduce accessibility.
\item Must be tested periodically.
\end{itemize}
\\
\hline

Final Recommendation &
Recommended because it is inexpensive, highly reliable, and complies with industrial safety standards while being readily available in Tunisia.
\\
\hline

\end{longtable}

%%%%%%%%%%%%%%%%%%%%%%%%%%%%%%%%%%%%%%%%%%%%%%%%%%%%%%%
\subsection{Warning Beacon and Audible Alarm}

\begin{longtable}{|p{4cm}|p{10cm}|}
\hline

\textbf{Parameter} & \textbf{Details} \\
\hline

Component &
AD22-22MSD LED Indicator with Integrated Audible Alarm \\
\hline

Function &
Provides both visual and audible warnings to indicate the operating state of the robot, including movement, emergency stop activation, fault conditions, and low-battery situations. \\
\hline

Alternative Options &
\begin{itemize}
\item PATLITE Industrial Signal Tower
\item WERMA KombiSIGN 40
\end{itemize}
\\
\hline

Technical Specifications &
\begin{itemize}
\item Operating Voltage: 24 VAC/DC and 220 VAC 
\item Indicator Color: Red 
\item Integrated Audible Alarm (Buzzer) 
\item Mounting Diameter: 22 mm 
\item Mounting Type: Panel Mount 
\item Technology: LED 
\item Quantity Required: 1
\end{itemize}
\\
\hline

Procurement &
Buy \\
\hline

Price &
Approximately:  10 TND
\\
\hline

Supplier / Link &
\begin{itemize}
\item Seli tn

\end{itemize}
\\
\hline

Availability &
Generally available \\
\hline

Delivery Difficulty &
Low \\
\hline

Compatibility &
Compatible with the 24 V electrical architecture of the robot and can be directly controlled by the STM32 microcontroller using a relay or transistor driver circuit. \\ 
\hline 

Software Support &
No dedicated software required. The device can be activated through digital outputs controlled by the microcontroller or ROS2 nodes. \\ 
\hline 

Risks &
\begin{itemize} 
\item Lower visibility compared to industrial signal towers. 
\item Fixed red color provides limited status indication. 
\item Audible level may be insufficient in noisy industrial environments. 
\end{itemize} \\ 
\hline 

Final Recommendation &
Recommended for Prototype V1 because it combines visual and audible warning functions in a single, low-cost device that satisfies the basic safety requirements of the prototype. \\ 
\hline

\end{longtable}

%%%%%%%%%%%%%%%%%%%%%%%%%%%%%%%%%%%%%%%%%%%%%%%%%%%%%%%
\subsection{Safety Relay}

\begin{longtable}{|p{4cm}|p{10cm}|}
\hline

\textbf{Parameter} & \textbf{Details} \\
\hline

Component &
Pilz PNOZ X2.8P Safety Relay \\
\hline

Function &
Monitors the emergency stop circuit and safely disconnects power to the drive system when an emergency condition or fault occurs. The relay provides hardware-based safety independent of the onboard computer and software. \\
\hline

Alternative Options &
\begin{itemize}
\item Omron G9SE-201 Safety Relay
\item Schneider Preventa XPS Safety Relay
\end{itemize}
\\
\hline

Technical Specifications &
\begin{itemize}
\item Supply Voltage: 24 VAC/DC
\item Safety Outputs: 3 Normally Open (NO)
\item Auxiliary Output: 1 Normally Closed (NC)
\item Single-channel or dual-channel emergency-stop monitoring
\item Short-circuit detection capability
\item DIN Rail Mounting
\item Response Time: $<$ 50 ms
\item Quantity Required: 1
\end{itemize}
\\
\hline

Procurement &
Buy \\
\hline

Price &
Approximately 600--900 TND (refurbished unit). \\
\hline

Supplier / Link &
Automation technics (on order)
\\
\hline

Availability &
Available on special order. Procurement may require an extended lead time depending on supplier availability and import conditions. \\
\hline

Delivery Difficulty &
Medium to High \\
\hline

Compatibility &
Compatible with 24 V emergency stop circuits, motor contactors, and industrial control architectures. Easily integrated into the robot's safety chain. \\
\hline

Software Support &
No software required. The relay operates independently of the onboard computer and ensures a hardware-based emergency shutdown mechanism. \\
\hline

Risks &
\begin{itemize}
\item The available unit is refurbished and may have limited warranty.
\item Requires proper wiring according to safety standards.
\item Additional cost compared with a simple relay-based shutdown circuit.
\end{itemize}
\\
\hline

Final Recommendation &
Recommended for Prototype V1 because it provides an industrial-grade and standards-compliant emergency shutdown mechanism while remaining simpler and less expensive than a complete safety PLC solution.
\\
\hline

\end{longtable}

%%%%%%%%%%%%%%%%%%%%%%%%%%%%%%%%%%%%%%%%%%%%%%%%%%%%%%%
\newpage
\section{Power System}

\subsection{Battery Pack}

\textbf{Role:} Provides the primary onboard power for the complete AMR-X system, supporting differential-drive motors, compute, sensors, and safety systems for $\geq 3$ hours continuous operation under nominal load ($1.0$ m/s cruise, 50 kg payload).

\textbf{Specifications to Meet:}
\begin{itemize}
\item Nominal Voltage: $24$ V DC
\item Capacity: $20$ Ah ($480$ Wh) minimum for Maxon EC45 motors (upgraded from $15$ Ah)
\item Chemistry: LiFePO$_4$ preferred for safety and cycle life
\item Built-in BMS: Over-current, over-temperature, over/under-voltage protection
\item Discharge Connectors: Suitable for continuous $30$--$50$ A draw and peak $80$--$100$ A transients
\end{itemize}

\begin{longtable}{|p{4cm}|p{10cm}|}
\hline
\textbf{Parameter} & \textbf{Details} \\
\hline

Component &
Custom LiFePO$_4$ $24$ V $20$ Ah Battery Pack (UPGRADED) \\
\hline

Function &
Provides primary onboard power for motors, compute, sensors, and safety systems. Supports $3+$ hours of continuous operation carrying $50$ kg payload at nominal $1.0$ m/s cruise speed. Upgraded to $20$ Ah (from $15$ Ah) to maintain endurance with higher-power Maxon EC45 motors ($70$ W vs $25$ W). \\
\hline

Alternative Options &
\begin{itemize}
\item Option B: Pre-made $24$ V Power Tool Battery (FLEX, Greenworks, Kobalt..) (insufficient capacity at $5$ Ah per pack; requires $4$ packs in parallel; heavy)
\item Option C: $24$ V LiPo Battery Pack (poor cycle life of $300$--$500$ cycles; safety concerns; not recommended)
\end{itemize}
\\
\hline

Technical Specifications &
\begin{itemize}
\item Nominal Voltage: $24.0$ V
\item Capacity: $20$ Ah ($480$ Wh) — UPGRADED from $15$ Ah
\item Chemistry: Lithium Iron Phosphate (LiFePO$_4$)
\item Dimensions: approximately $180 \times 180 \times 100$ mm
\item Mass: approximately $5.7$ kg ($20$ Ah)
\item Cycle Life: $2000$--$3000$ cycles
\item Built-in BMS: $60$--$80$ A continuous, $100$--$150$ A peak
\item Round-trip Efficiency: approximately $95\%$
\item Charge Connector: XT90 or Anderson PowerPole
\item Quantity Required: 1
\end{itemize}
\\
\hline

Procurement &
Buy \\
\hline

Price &
Approximately $1800$--$2200$ TND (upgraded from $1500$--$2000$). \\
\hline

Supplier / Link &
\begin{itemize}
\item requested from GPE Tunisia 
\item SeeepShop Tunisia 
\end{itemize}
\\
\hline

Availability &
Increasingly available from major distributors. Custom packs have lead time. \\
\hline

Delivery Difficulty &
Medium ($2$--$4$ weeks for custom pack) \\
\hline

Compatibility &
Fully compatible with Pololu VNH5019 motor driver ($60+$ A BMS rating). Works with $24$ V distribution system. XT90 connectors standard for industrial applications. Supports $70$ W Maxon EC45 motors (vs. $25$ W JGA25-370). \\
\hline

Software Support &
BMS provides autonomous protection. No software control required. Battery Management System monitors voltage, current, and temperature independently. \\
\hline

Risks &
\begin{itemize}
\item Customization lead time ($2$--$4$ weeks)
\item Heavier than Li-Po ($5$--$6$ kg vs. $3$--$4$ kg) but better for stability and cycle life
\item Requires external charger (PSU or dedicated battery charger)
\item Must be mounted centrally and low for centre-of-gravity optimisation
\end{itemize}
\\
\hline

Final Recommendation &
\textbf{STRONGLY RECOMMENDED (upgraded capacity).} LiFePO$_4$ chemistry is safe and durable ($2000+$ cycles), built-in BMS manages protection autonomously, $480$ Wh capacity ($20$ Ah) maintains $3+$ hour endurance requirement with higher-power Maxon EC45 motors, fits mass budget, and is increasingly available in Tunisia. Upgrade from $15$ Ah to $20$ Ah is REQUIRED to support $70$ W motors and maintain endurance target. Optimal choice for long-term prototype operation ($3+$ years). \\
\hline

\end{longtable}

%%%%%%%%%%%%%%%%%%%%%%%%%%%%%%%%%%%%%%%%%%%%%%%%%%%%%%%
\subsection{Power Distribution and DC-DC Converters}

\textbf{Role:} Routes $24$ V battery power safely to all subsystems (motors, compute, sensors, safety) with appropriate overcurrent protection, voltage conversion, and electromagnetic interference filtering.

\textbf{Specifications to Meet:}
\begin{itemize}
\item Main Fuse: $80$ A (battery short-circuit protection)
\item Motor Power Rail: $30$ A fused (motor driver protection)
\item Compute Regulator: $24$ V $\rightarrow$ $12$ V at $5$ A (Jetson input)
\item Sensor Regulator: $24$ V $\rightarrow$ $5$ V at $5$ A (all sensors and safety beacon)
\item Wiring: 4/6/8/10 AWG depending on current rating
\item EMI Filtering: Ferrite clamps on motor lines
\end{itemize}

\begin{longtable}{|p{4cm}|p{10cm}|}
\hline
\textbf{Parameter} & \textbf{Details} \\
\hline

Component &
$24$ V Power Distribution System with Protection and DC-DC Conversion \\
\hline

Function &
Safely distributes battery power to three independent rails: motor power ($24$ V direct, $30$ A), compute power ($24$ V $\rightarrow$ $12$ V regulated), and sensor power ($24$ V $\rightarrow$ $5$ V regulated). Includes overcurrent protection, EMI filtering, and voltage regulation. Supports higher current draw from Maxon EC45 motors (vs. JGA25-370). \\
\hline

Sub-Components &
\begin{itemize}
\item Main Fuse: ANL $80$ A cartridge + holder
\item Motor Fuse: ANL $30$ A cartridge
\item Compute Regulator: XL4005 buck converter ($24$ V $\rightarrow$ $12$ V, $5$ A)
\item Sensor Regulator: HLK-5M05 buck converter ($24$ V $\rightarrow$ $5$ V, $5$ A)
\item Wiring: $4$ AWG (main), $6$ AWG (motor), $8$ AWG (compute), $10$ AWG (sensors)
\item Connectors: XT90 (battery), Anderson PowerPole (distribution)
\item Capacitors: $100$ $\mu$F $\times$ $3$ (filtering)
\item Ferrite Clamps: Toroid clamps for motor lines (EMI suppression)
\end{itemize}
\\
\hline

Alternative Options &
\begin{itemize}
\item Option A: DIY MOSFET H-Bridge with discrete components (requires PCB design; risky for V1 timeline)
\item Option B: Custom PCB (integrates all components, cleaner but requires design)
\end{itemize}
\\
\hline

Technical Specifications &
\begin{itemize}
\item System Voltage: $24$ V DC (distributed)
\item Main Protection: $80$ A fuse (battery short-circuit)
\item Motor Rail: $30$ A fused, direct $24$ V to motor driver
\item Compute Rail: $24$ V $\rightarrow$ $12$ V at $5$ A, approximately $85\%$ efficiency, $<5\%$ ripple
\item Sensor Rail: $24$ V $\rightarrow$ $5$ V at $5$ A, approximately $90\%$ efficiency
\item Wiring: Mixed gauge ($4$--$10$ AWG) per current rating
\item EMI Filtering: Ferrite clamps on motor power lines
\item Quantity Required: $1$ complete system
\end{itemize}
\\
\hline

Procurement &
\begin{itemize}
    \item \textbf{Option A: Modular Components} Purchase fuse holders, DC-DC converters, connectors, wiring, and ferrite clamps; assemble into a distribution system.
    \item \textbf{Option B: Custom PCB} Integrates fuses, converters, and connectors into a single board. Cleaner and compact but requires design, fabrication, and testing.
\end{itemize} \\
\hline

Price &
 \begin{itemize}
    \item Option A: 540 TND
    \item Option B: 800--1,000 TND
\end{itemize}\\
\hline

Supplier / Link &
\begin{itemize}
\item Local electronics shops: fuses, capacitors, ferrite clamps
\item 2B TRADING: wiring, connectors, buck converter modules
\item DigiKey: XL4005, HLK-5M05 converter modules
\end{itemize}
\\
\hline

Availability &
All components readily available (stock items, under 1 week). 
If option B depends on the PCB design delivery ( more than 3 layers PCB needs an international supplier)\\
\hline

Delivery Difficulty &
Low (buck converters and fuses are standard parts) \\
\hline

Compatibility &
Fully compatible with $24$ V LiFePO$_4$ battery, Pololu VNH5019 motor driver, NVIDIA Jetson ($12$ V barrel jack input), STM32 via $5$ V logic rail, and all sensors. Wiring gauges are suitable for continuous motor draw and peak transients. Supports higher current demand from Maxon EC45 motors. \\
\hline

Software Support &
Power distribution operates autonomously (no software control). DC-DC converters self-regulate. BMS and fuses provide hardware protection independent of firmware. \\
\hline

Risks &
\begin{itemize}
\item Regulator dropout if overloaded (mitigation: $5$ A rating is $2$--$10$ $\times$ motor duty)
\item EMI noise on sensor lines if motor cables are routed nearby (mitigation: ferrite clamps and separate routing)
\item Fuse blowout if short circuit occurs (mitigation: design fuse as protective device, not fault indicator)
\end{itemize}
\\
\hline

Final Recommendation &
Recommended because the tiered architecture (main fuse, per-rail fuses, dual voltage regulators) provides redundant protection while keeping cost low (approximately 540 TND). Buck converters are proven, efficient designs. Ferrite clamps suppress motor EMI. Wiring gauges ensure safety margins on all current paths. Modular design allows testing each subsystem independently. Supports higher current draw from $70$ W Maxon EC45 motors. \\
\hline

\end{longtable}

%%%%%%%%%%%%%%%%%%%%%%%%%%%%%%%%%%%%%%%%%%%%%%%%%%%%%%%
\newpage
\section{Motion System}

\subsection{Drive Motors with Gearbox}

\textbf{Role:} Provide primary motive power for differential drive with sufficient torque to handle rated payload ($50$ kg), future modular attachments (arm/gripper up to $10$ kg), and transient ramps. Two identical motors drive the $180$ mm wheels at the target speed range ($0.8$--$1.5$ m/s) while maintaining excellent load-carrying capacity and climb performance.

\textbf{Specifications to Meet:}
\begin{itemize}
\item Type: $24$ V brushless DC motor with integrated planetary gearbox
\item Nominal Power: $70$ W per motor (sufficient for warehouse load)
\item Output Torque: $8$--$10$ N$\cdot$m per wheel (strong enough for payload + future arm)
\item Wheel Output Speed: $100$--$150$ RPM (to achieve $0.8$--$1.5$ m/s on $180$ mm wheels)

\item Efficiency: $\geq 75\%$ overall (motor + gearbox)
\item Quantity Required: $2$ (identical)
\end{itemize}

\begin{longtable}{|p{4cm}|p{10cm}|}
\hline
\textbf{Parameter} & \textbf{Details} \\
\hline

Component &
Maxon EC 45 Flat Brushless Motor ($70$ W @ $24$ V) + Maxon GP 42C Planetary Gearbox ($33:1$) \\
\hline

Function &
Provides high-torque motive power for differential drive. Brushless motor with integrated planetary gearbox produces $8$--$10$ N$\cdot$m output torque, enabling reliable operation under full payload ($50$ kg) and supporting future modular attachments (arms, grippers) up to $10$ kg additional mass. Maintains $1.0$ m/s nominal wheel speed for warehouse operation. \\
\hline

Alternative Options &
\begin{itemize}
\item Option A: ZLTECH 4-inch Hub Motor ($100$ W, $3.0$ N$\cdot$m, direct-drive, budget-friendly, slower at $0.28$ m/s)
\item Option B: FAULHABER 3242G 45W + Series 26/4 Gearbox ($7$--$12$ N$\cdot$m, maximum torque density, German precision, higher cost)
\end{itemize}
\\
\hline
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

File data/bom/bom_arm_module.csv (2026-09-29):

item_id | subsystem | component_name | function | decision_type | candidate_part | supplier | quantity | unit | unit_cost | currency | status | owner | source_link | notes
ARM-001 | Structure | TBD | TBD | TBD | TBD | TBD | TBD | TBD | TBD | TBD | TBD | TBD | TBD | TBD
ARM-002 | Actuation | TBD | TBD | TBD | TBD | TBD | TBD | TBD | TBD | TBD | TBD | TBD | TBD | TBD
ARM-003 | End Effector | TBD | TBD | TBD | TBD | TBD | TBD | TBD | TBD | TBD | TBD | TBD | TBD | TBD
ARM-004 | Control | TBD | TBD | TBD | TBD | TBD | TBD | TBD | TBD | TBD | TBD | TBD | TBD | TBD

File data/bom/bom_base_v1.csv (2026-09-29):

item_id | subsystem | component_name | function | decision_type | candidate_part | supplier | quantity | unit | unit_cost | currency | status | source | notes
BASE-TBD-001 | TBD | TBD | TBD | TBD | TBD | TBD | TBD | TBD | TBD | TND | Not selected yet | TBD | Final BOM will be filled after component validation and prototype assumptions are reviewed.

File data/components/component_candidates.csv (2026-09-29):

component_id | component | function | recommended_option | alternative_options | procurement | price | supplier_or_link | availability | delivery_difficulty | compatibility | software_support | risks | final_recommendation
COMP-001 | DC Gear Motor | Provides propulsion for the robot and generates encoder feedback for odometry and speed estimation | JGB37-520 12V/24V DC Gear Motor with Quadrature Encoder | JGA25-370 DC Gear Motor with Encoder; 775 DC Gear Motor; BLDC Hub Motor | Buy | 33,000 TND | Little-Son Tunisia; souilah-electronique | Available locally (limited stock) and imported | Low to Medium | High compatibility for a warehouse AMR prototype with payloads up to approximately 20-30 kg | Supported through ESP32 STM32 Arduino and ROS2 odometry packages | Encoder quality varies by supplier; Gearbox wear under heavy loads; Torque may be insufficient if payload increases significantly | Recommended for Prototype V1 due to a good balance between cost availability torque and encoder integration
COMP-002 | Motor Driver | Controls motor direction and speed using PWM signals from the microcontroller | BTS7960 43A H-Bridge Motor Driver | Cytron MDDS30; Sabertooth 2x25; IBT-2 Motor Driver | Buy | 20.500 TND | Little-Son Tunisia; smart-innovation | Usually available locally and imported | Low | Fully compatible with ESP32 and Raspberry Pi based architectures | Compatible with Arduino IDE ESP-IDF STM32CubeIDE and ROS-based control systems | Cooling may be required under continuous high current; Quality differs between manufacturers | Recommended for Prototype V1 because of its low cost and sufficient power handling
COMP-003 | Drive Wheels | Transfers motor torque to the floor and provides robot mobility | 150 mm Rubber Wheel with Metal Hub | 125 mm Rubber Wheel; 200 mm Industrial Wheel; Pneumatic Wheel | Buy or Modify locally | 23,900 TND | Little-Son Tunisia; AliExpress | Available locally | Low | Suitable for indoor warehouse floors and differential-drive navigation | Not required | Wheel slippage on dusty floors; Wear after extended operation | Recommended due to simplicity durability and local availability
COMP-004 | Caster Wheel | Provides passive support and stability while allowing free movement | 75-100 mm Swivel Caster Wheel | Ball Caster; Omni Wheel; Fixed Support Wheel | Buy | 46.500 TND | Local hardware stores; Industrial suppliers; AliExpress | Widely available locally | Very Low | Suitable for a differential-drive mobile robot | Not required | May generate vibration on uneven floors; Can reduce maneuverability if oversized | Recommended for Prototype V1 because it is inexpensive simple and easy to replace

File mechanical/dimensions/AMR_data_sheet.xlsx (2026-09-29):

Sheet: BaseDimensions
AMR — Base Dimensions & Specifications
Master parameter list for the robot chassis, drive system, mass budget, module interface, sensors and performance limits — each with its config name, value, status, owner and source.
Parameter | Xacro / config name | Value | Unit | Status | Owner / who provides | How to determine / source
BASE & CHASSIS
Base length | base_length | 800 | mm | Confirmed | Mahmoud/Meriem | AMR Specifications
Base width | base_width | 600 | mm | Confirmed | Mahmoud/Meriem | AMR Specifications
Base height (no module) | base_height | 420 | mm | Confirmed | Mahmoud/Meriem | AMR Specifications
Ground clearance | ground_clearance | 40 | mm | Confirmed | Mahmoud/Meriem | AMR Specifications
Chassis material | chassis_material |  | - | Open | Ahmed/Adam | Decide in concept phase (steel vs aluminium) from material & manufacturing selection.
Frame profile / wall thickness | frame_profile |  | mm | Open | Ahmed/Adam | From the structural concept and chosen manufacturing method.
Top platform thickness | top_plate_thickness |  | mm | Open | Ahmed/Adam | From plate selection and the payload load path (75 kg design load).
WHEELS & MOBILITY (differential drive)
Drive architecture | - | differential drive | - | Confirmed | Mahmoud/Meriem | AMR Specifications
Number of drive wheels | n_drive_wheels | 2 | - | Confirmed | Mahmoud/Meriem | Centrally positioned.
Drive wheel diameter | drive_wheel_diameter | 180 | mm | Confirmed | Mahmoud/Meriem | Final value from the SELECTED wheel datasheet.
Drive wheel radius | wheel_radius | 90 | mm | Confirmed | Mahmoud/Meriem | Auto = diameter / 2.
Drive wheel width | drive_wheel_width | 50 | mm | Confirmed | Mahmoud/Meriem | From the selected wheel / tyre datasheet.
Wheel separation (track) | wheel_separation | 520 | mm | Confirmed | Mahmoud/Meriem | Distance between the two drive-wheel contact centres. Set in the layout, within the 600 mm width. KEY diff_drive_controller param.
Number of casters | n_casters | 4 | - | Confirmed | Mahmoud/Meriem | AMR Specifications
Caster diameter | caster_diameter | 100 | mm | Confirmed | Mahmoud/Meriem | Final value from the selected caster datasheet.
Caster offset (x from centre) | caster_offset_x | 330 | mm | Confirmed | Mahmoud/Meriem | 4 casters
Wheelbase (caster span) | wheelbase | 660 | mm | Confirmed | Mahmoud/Meriem | Front-to-rear caster contact spacing, from your layout. Used in the break-over check below.
MASS & CENTRE OF GRAVITY
Rated payload capacity | payload_capacity | 50 | kg | Confirmed | Mahmoud/Meriem | Module + payload the robot carries.
Structural design load | design_load | 75 | kg | Confirmed | Mahmoud/Meriem | Size the structure to this, not to 50 kg.
Max target unloaded mass | max_unloaded_mass | 80 | kg | Confirmed (target) | Mahmoud/Meriem | Budget. Track the actual against this.
Actual unloaded mass | actual_unloaded_mass |  | kg | Open | Ahmed/Adam | Compute in CAD mass properties once parts are placed. Rolls up the Component Volumes sheet.
CoG x (from centre) | cog_x |  | mm | Open | Ahmed/Adam | From CAD mass properties after component placement. Keep near 0.
CoG y (from centre) | cog_y |  | mm | Open | Ahmed/Adam | From CAD. Keep near 0.
CoG height z (from floor) | cog_z |  | mm | Open | Ahmed/Adam | From CAD. Keep LOW — drives tip stability on the 5 deg ramp.
MODULE INTERFACE & DOCKING
Module interface length | module_if_length | 500 | mm | Provisional | Module group (Yassmine, Chaima) | Baseline. Confirm against the planned arm/shelf/compartment/inspection modules.
Module interface width | module_if_width | 400 | mm | Provisional | Module group | Baseline.
Module interface height (floor) | module_if_height | 420 | mm | Provisional | Module group | Equals base height in baseline. Confirm.
Module position | module_position | centred | - | Confirmed | Baseline | Centred above the chassis.
Locking mechanism | module_lock_type |  | - | Future | Module group | Concept comes later — reserve space now.
Docking connector position | dock_connector_pos |  | - | Future | Module group + Electrical | Reserve location now; pin spec later with electrical.
Module power/data interface | module_power_data |  | - | Future | Electrical & Embedded team | 24 V rail + data bus spec. Get from the electrical team.
Human interaction height | human_interaction_height | 750-1000 | mm | Future | Module group | Provided by the installed module later. Informational — do not raise the chassis for it.
PERFORMANCE & LIMITS
Normal speed (min) | speed_normal_min | 0.8 | m/s | Confirmed | Baseline
Normal speed (max) | speed_normal_max | 1.2 | m/s | Confirmed | Baseline
Maximum design speed | speed_max | 1.5 | m/s | Confirmed | Baseline | Navigation max speed.
Reduced safety speed | speed_safety | 0.3 | m/s | Confirmed | Baseline | Max speed in the safety state.
Minimum endurance | endurance_min | 3 | h | Confirmed | Baseline | Drives battery sizing (electrical team).
Maximum ramp | max_ramp | 5 | deg | Confirmed | Baseline | Used in the break-over and tip checks.
Operating surface | surface | indoor concrete / epoxy | - | Confirmed | Baseline
Min operating aisle width | min_aisle_width | 1500 | mm | Confirmed | Baseline | Equal to 1.5 m. Used in the turning-clearance check.
Min passage width | min_passage_width | 900 | mm | Confirmed | Baseline | Used in the passage-clearance check.
System voltage | system_voltage | 24 | V | Confirmed | Baseline / Electrical
DERIVED / SANITY CHECKS (auto — do not type over)
Footprint diagonal | footprint_diag | 1000 | mm | Derived | - | Auto = sqrt(length^2 + width^2).
Swept radius (rotate in place) | swept_radius | 500 | mm | Derived | - | Auto = diagonal / 2. Robot rotating about its centre.
Aisle clearance each side | aisle_clearance_side | 250 | mm | Derived | - | Auto. Want > 0 with margin.
Passage clearance | passage_clearance | 300 | mm | Derived | - | Auto = passage - base width. Want > 0.
Ramp break-over angle | breakover_deg | fill wheelbase | deg | Derived | - | Auto. Want > max ramp. Shows a prompt until wheelbase is filled.

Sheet: WheelsPos
AMR — Wheel & Caster Positions
Mounting coordinates of the two drive wheels and four casters relative to the chassis-centre origin O, alongside the key derived edge and clearance values.
 |  |  |  |  |  |  |  | The origin O sits at the geometric centre of the 800 × 600 footprint, on the floor plane
 | Element | X (mm) | Y (mm) | Z axle (mm) | Wheel Ø (mm) | Width (mm) | Mounting note
 | Drive wheel — LEFT | 0 | 260 | 90 | 180 | 50 | Mounted on the central drive axle (X = 0) and coupled to the gearbox output shaft via a flexible coupling. | KEY DERIVED VALUES
 | Drive wheel — RIGHT | 0 | -260 | 90 | 180 | 50 | Mounted on the central drive axle (X = 0) and coupled to the gearbox output shaft via a flexible coupling. | Drive-wheel outer edge (|Y|) | 285
 | Caster — FRONT-LEFT | 330 | 230 | 50 | 100 | 25 mm à 35 mm | Mounted as 360° swivel casters using M10 threaded stems integrated into recessed chassis pockets. | Clearance wheel edge → body side | 15
 | Caster — FRONT-RIGHT | 330 | -230 | 50 | 100 | 25 mm à 35 mm | Mounted as 360° swivel casters using M10 threaded stems integrated into recessed chassis pockets. | Drive-unit inner end (|Y|) | 108
 | Caster — REAR-LEFT | -330 | 230 | 50 | 100 | 25 mm à 35 mm | Mounted as 360° swivel casters using M10 threaded stems integrated into recessed chassis pockets. | Caster contact (trailing, |X|) | 365
 | Caster — REAR-RIGHT | -330 | -230 | 50 | 100 | 25 mm à 35 mm | Mounted as 360° swivel casters using M10 threaded stems integrated into recessed chassis pockets. | Clearance caster trailing → body end | 35
 |  |  |  |  |  |  |  | Caster lateral position (|Y|) | 230
 |  |  |  |  |  |  |  | Clearance caster → body side | 35

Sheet: Components
 |  | AMR — Component Inventory
 |  | Selected hardware components with overall dimensions (L×W×H), mass and source notes, used for internal layout and the unloaded-mass roll-up.
Component | Selected model | L (X) | W (Y) | H (Z) | Mass (g) | Source / note | Comments
Main computer | NVIDIA Jetson Orin Nano Dev Kit | 100 | 79 | 35 | 176 | NVIDIA datasheet (bare carrier 100x79; 103x90.5x35 w/ base)
Microcontroller | STM32 Nucleo-F446RE | 82 | 70 | 20 | 60 | Nucleo-64 form factor
2*LiDAR | RPLIDAR A2M12 | Ø76 | Ø76 | 41 | 190 | Slamtec datasheet — needs clear 360° horizon
Depth camera | Intel RealSense D435i | 90 | 25 | 25 | 72 | Intel datasheet — front facing
RGB camera | Logitech C920 | 94 | 43 | 71 | 162 | incl. clip; front facing
IMU | BNO055 breakout | 20 | 27 | 4 | 3 | tiny PCB; mount low & central
Ultrasonic x4 | Industrial M18 | Ø18 | Ø18 | ~70 | ~50 | M18 threaded barrel; 4 around perimeter
Drive motor | Maxon EC45 flat 70W | Ø45 | Ø45 | 27 | 141 | Maxon datasheet (note: report said 75g)
Gearbox | Maxon GP42C 33:1 | Ø42 | Ø42 | 70 | 460 | Maxon datasheet, 3-stage (report said 36mm/0.35kg)
Flexible coupling | Oldham/jaw | Ø30 | Ø30 | 30 | 40 | between gearbox output & wheel
Motor driver | Pololu VNH5019 dual | 51 | 51 | 18 | 30 | carrier module
Battery pack | Custom LiFePO4 24V 20Ah | 180 | 180 | 100 | 5700 | report figure — SQUARE pack fouls motors (see 06) | VERIFY DIMENSIONS ??
Compute regulator | XL4005 buck | 45 | 30 | 15 | 25 | 24→12V 5A
Sensor regulator | HLK-5M05 buck | 32 | 20 | 12 | 20 | 24→5V
Main fuse | ANL 80A + holder | 85 | 45 | 40 | 80 | battery short-circuit protection
Safety relay | Pilz PNOZ X2.8P | 94 | 22.5 | 121 | 150 | DIN-rail; narrow 22.5mm housing
E-stop | Schneider XB2-BS542 | Ø40 | Ø40 | 65 | 60 | 22mm mount; mushroom head
Warning beacon | AD22-22MSD LED+buzzer | Ø22 | Ø22 | 60 | 40 | 22mm mount; top-most point

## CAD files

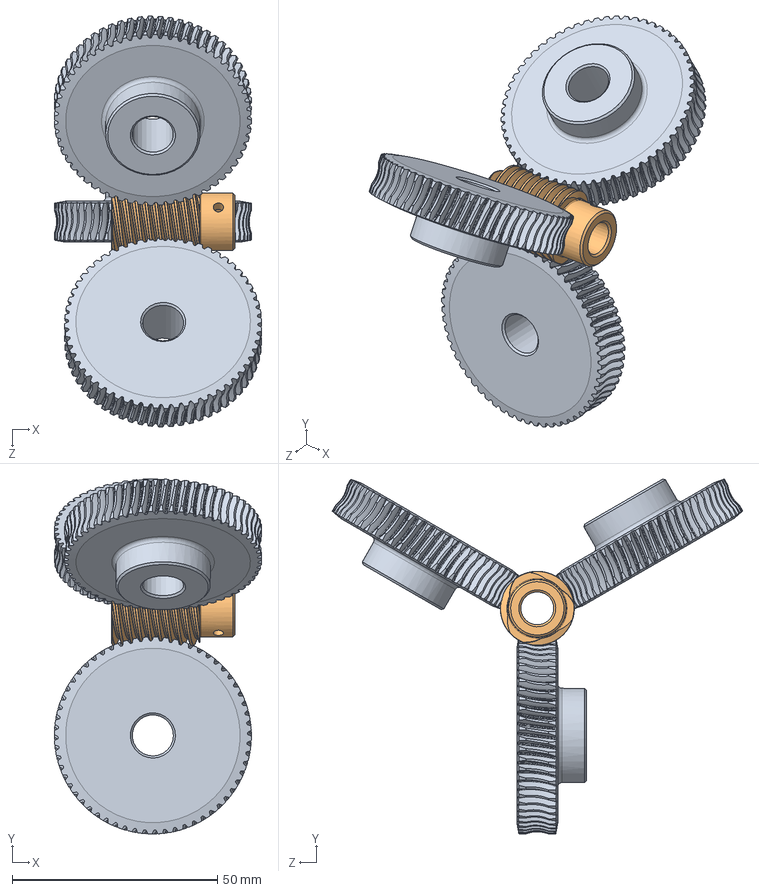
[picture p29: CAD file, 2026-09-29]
modules/arm_module/design/3-finger-gripper-2.snapshot.1/Worm Assembly.SLDASM
50.5 x 86.5 x 100.0 mm
Gear x 3
Worm Gear

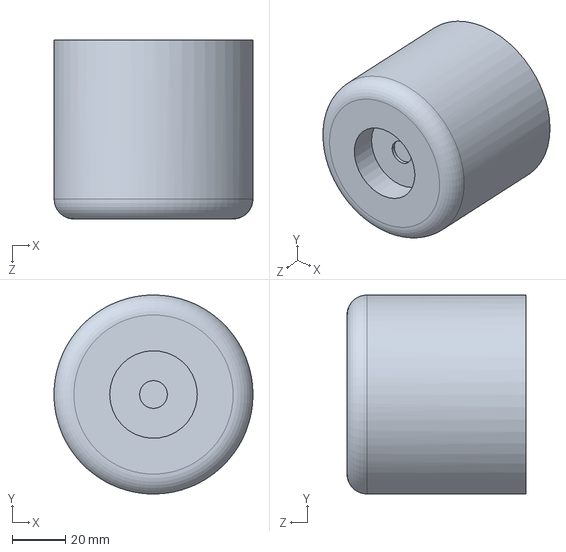
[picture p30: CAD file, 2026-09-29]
modules/arm_module/design/3-finger-gripper-2.snapshot.1/Main Arm Body.SLDPRT
75.0 x 75.0 x 67.5 mm

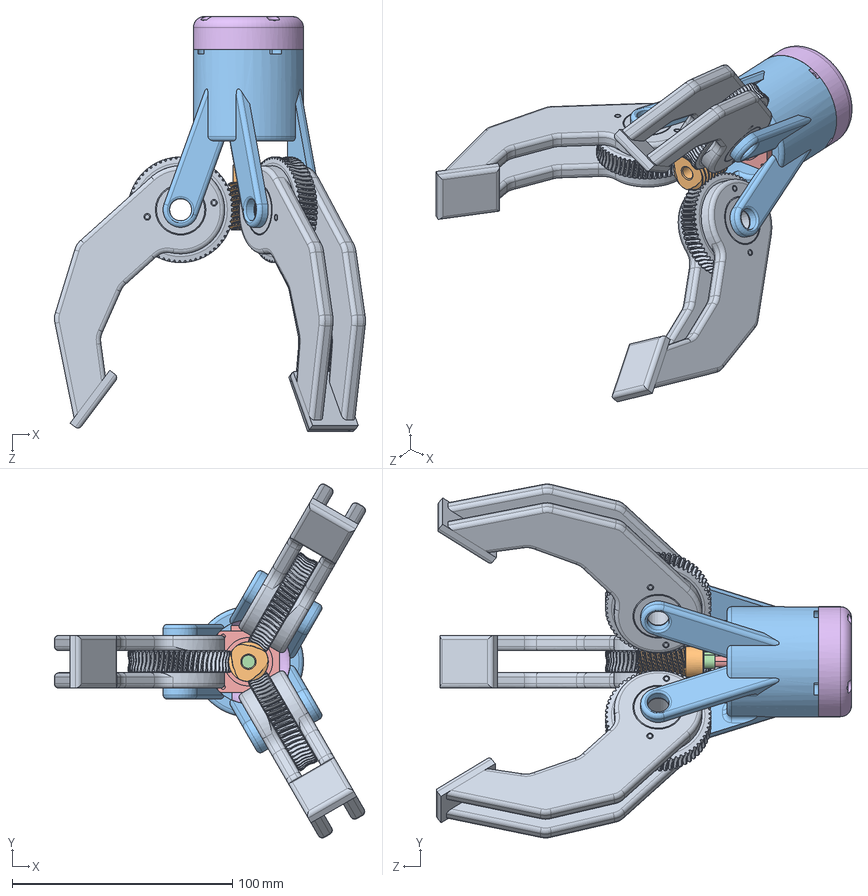
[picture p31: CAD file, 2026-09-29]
modules/arm_module/design/3-finger-gripper-2.snapshot.1/Final Assembly 1.SLDASM
141.3 x 160.8 x 188.5 mm
Gear x 3
Worm Gear
Housing
Key
stepper motor
Arm Cap

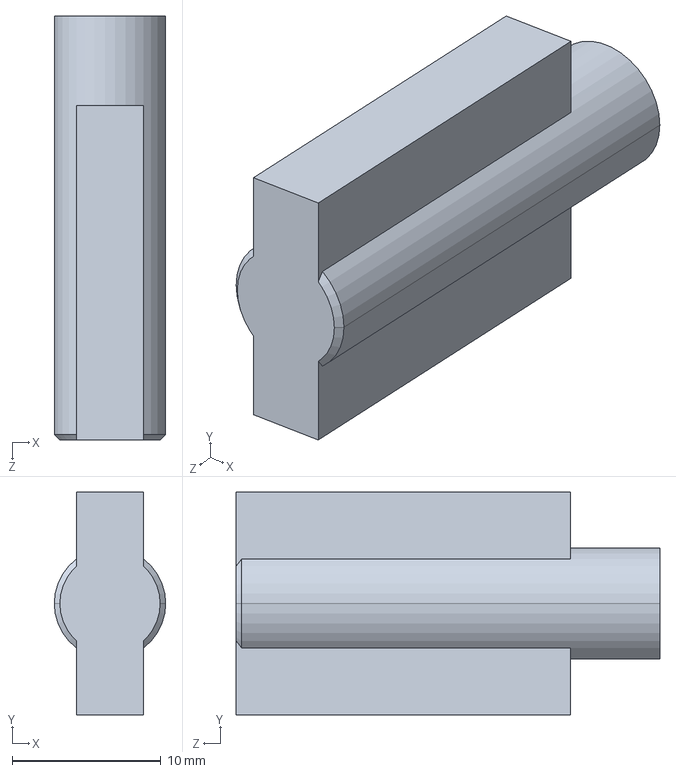
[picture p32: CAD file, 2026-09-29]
modules/arm_module/design/3-finger-gripper-2.snapshot.1/Main Arm Rotor.SLDPRT
7.50 x 15.0 x 28.5 mm

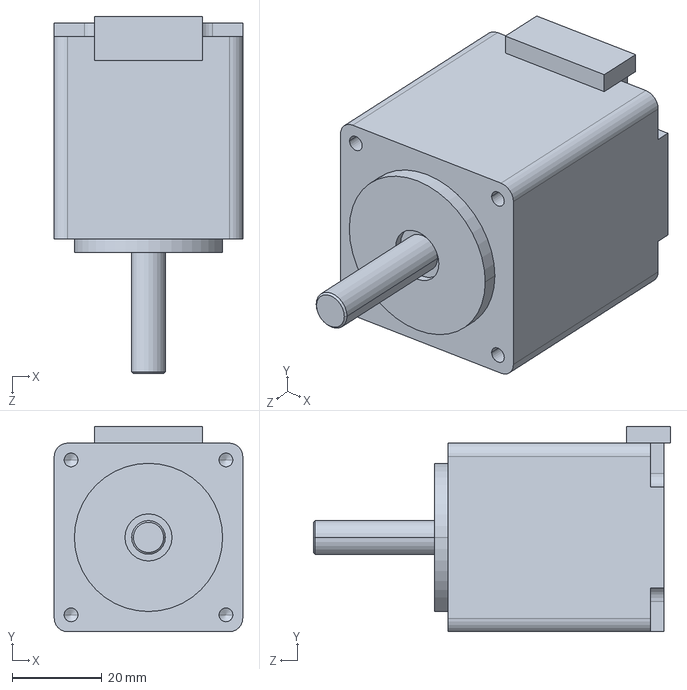
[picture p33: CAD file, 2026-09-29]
modules/arm_module/design/3-finger-gripper-2.snapshot.1/stepper motor.SLDPRT
42.0 x 45.8 x 79.5 mm

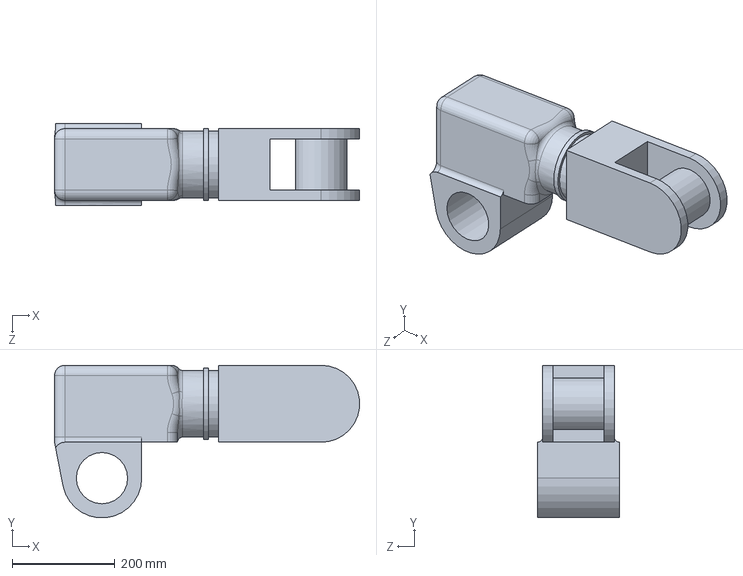
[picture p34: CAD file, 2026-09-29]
modules/arm_module/design/ROBOTIC_ARM/LINK 3.SLDPRT
594.6 x 297.1 x 160.0 mm

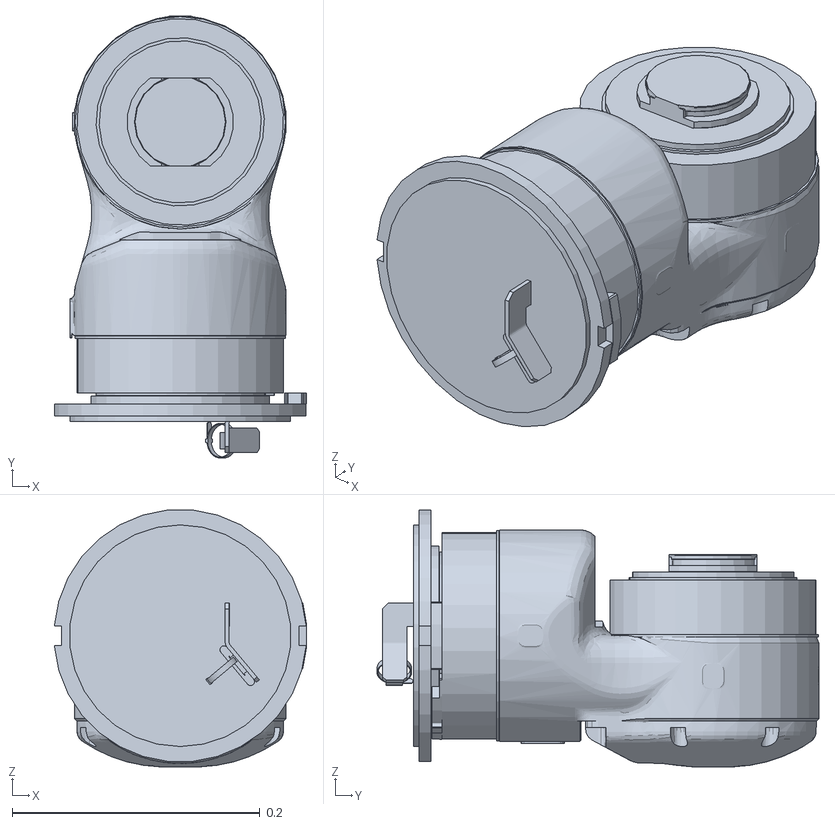
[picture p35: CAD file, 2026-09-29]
modules/dual_arm_model+urdf/dual_arm/meshes/shoulderR_1.STL
0.204 x 0.357 x 0.207

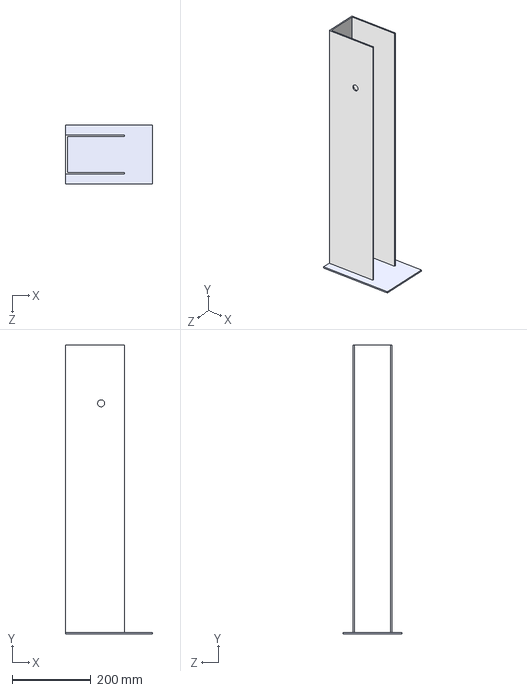
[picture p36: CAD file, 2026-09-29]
modules/dual_arm_model+urdf/simple-lifter-mechanism-1.snapshot.34/body.STEP
220.0 x 734.0 x 150.0 mm

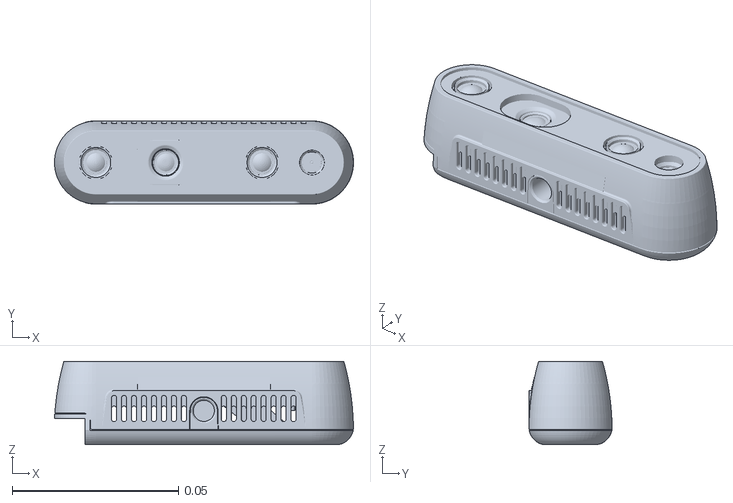
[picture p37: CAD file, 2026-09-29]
robotics/arm_description/meshes/d435/visual/d435.stl
0.0899 x 0.025 x 0.0251

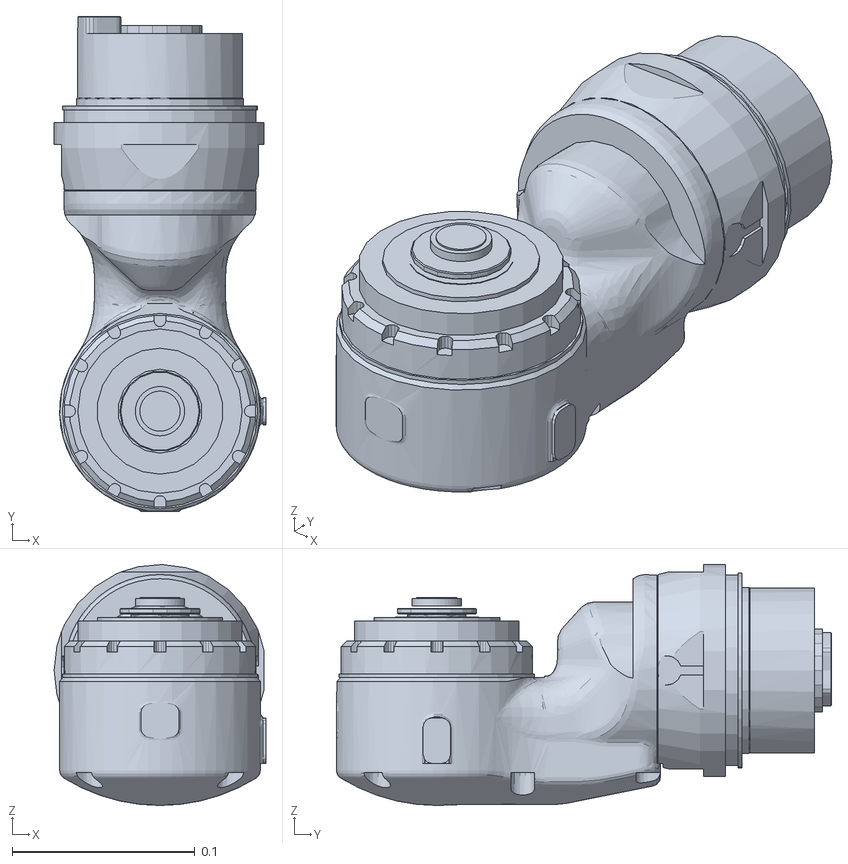
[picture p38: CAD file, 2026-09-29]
robotics/dual_arm_description/meshes/shoulder_5.STL
0.116 x 0.271 x 0.132

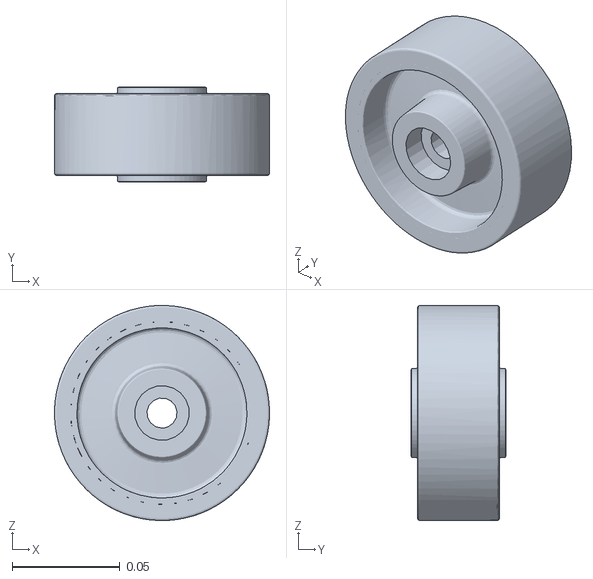
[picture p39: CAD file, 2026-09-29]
robotics/robot_description/meshes/BR_Caster_Wheel_Link.STL
0.0999 x 0.044 x 0.1

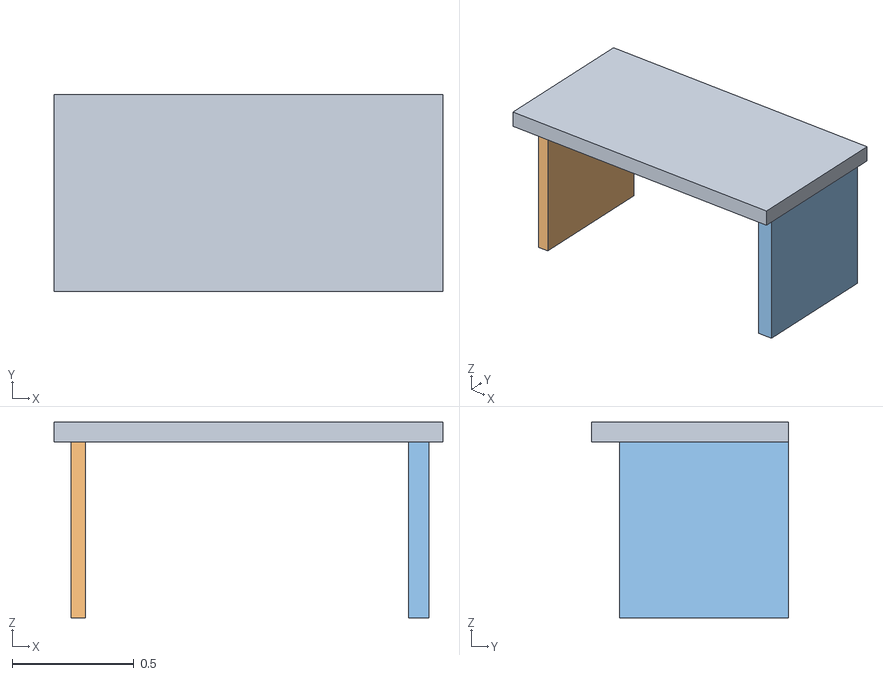
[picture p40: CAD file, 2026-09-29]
robotics/simulation/fuel_models/AdjTable/meshes/AdjTable_Col.obj
1.60 x 0.812 x 0.804
Cube_Cube.001
Cube.001_Cube.002
Cube.002_Cube.003

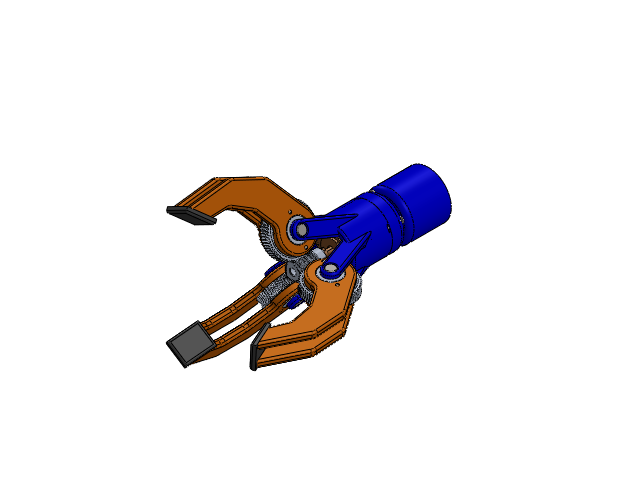
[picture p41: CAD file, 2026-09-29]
modules/arm_module/design/3-finger-gripper-2.snapshot.1/3 Finger Gripper Final Assembly.SLDASM
Main Arm Body
Main Arm Rotor
Arm Cap
Housing
stepper motor
Key
Worm Gear
Gear x 3
Finger Pin x 3
screw x 4

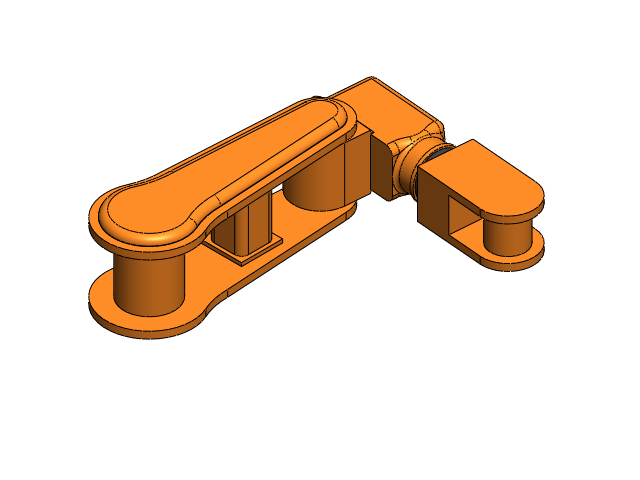
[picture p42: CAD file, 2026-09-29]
modules/arm_module/design/ROBOTIC_ARM/LINK 2&3.SLDASM
LINK 2
LINK 3

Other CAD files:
modules/arm_module/design/ROBOTIC_ARM/Assem2.SLDASM
modules/dual_arm_model+urdf/laboratory-robot-1.snapshot.2/csda10f_asm.stp.SLDASM
modules/arm_module/design/ROBOTIC_ARM/ABB_ROBOTIC_ARM.SLDASM
modules/dual_arm_model+urdf/laboratory-robot-1.snapshot.2/SBASE_AXIS.stp.SLDPRT
modules/arm_module/design/3-finger-gripper-2.snapshot.1/Arm Cap.SLDPRT
modules/arm_module/design/3-finger-gripper-2.snapshot.1/Finger Pin.SLDPRT
modules/arm_module/design/3-finger-gripper-2.snapshot.1/Housing.SLDPRT
modules/arm_module/design/3-finger-gripper-2.snapshot.1/Key.SLDPRT
modules/arm_module/design/3-finger-gripper-2.snapshot.1/Worm Gear.SLDPRT
modules/arm_module/design/ROBOTIC_ARM/ABB_ROBOTIC_ARM - Copy.SLDASM
modules/arm_module/design/ROBOTIC_ARM/BASE.SLDPRT
modules/arm_module/design/ROBOTIC_ARM/LINK 1.SLDPRT
modules/arm_module/design/ROBOTIC_ARM/LINK 2.SLDPRT
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

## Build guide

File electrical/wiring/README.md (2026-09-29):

# Wiring

Wiring diagrams and harness design.

## Purpose

Design electrical harness, connector selection, and routing for all subsystems.

## Areas

- Harness layout and routing
- Connector selection and standards
- Wire gauge and shielding
- Power distribution routing
- Signal integrity and EMI considerations

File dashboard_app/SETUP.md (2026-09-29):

# AMR-X Dashboard Setup

This guide covers the current dashboard stack in this repository:

- PostgreSQL 16 in Docker
- FastAPI backend in the shared repository-root `.venv`
- React/Vite frontend
- Optional rosbridge_server if you want live robot telemetry from ROS 2

The supported dashboard commands are run from the repository root.

## First-Time Setup

1. Prepare the shared Python environment and frontend packages:

```bash
npm run setup:dashboard
```

This creates or reuses the root `.venv`, installs the backend dependencies into it, creates `.env` from `.env.example` when needed, and installs the frontend packages.

2. Start PostgreSQL and wait for it to become healthy:

```bash
npm run dashboard:db
npm run dashboard:db:status
```

3. Start the backend:

```bash
npm run dashboard:backend
```

Open <http://127.0.0.1:8000/docs> to verify the API.

4. Start the frontend:

```bash
npm run dashboard:frontend
```

Open <http://localhost:5173/>.

## Daily Startup

Start the services you need from the repository root:

```bash
npm run dashboard:db
npm run dashboard:backend
npm run dashboard:frontend
```

For ROS-connected testing, start rosbridge in a separate terminal after sourcing the ROS 2 workspace:

```bash
source /opt/ros/jazzy/setup.bash
ros2 launch rosbridge_server rosbridge_websocket_launch.xml
```

## Legacy Standalone Page

The old browser prototype is still available at [robotics/dashboard_app/dashboard.html](../robotics/dashboard_app/dashboard.html). It connects directly to rosbridge on `ws://localhost:9090` and is separate from the supported React/Vite dashboard.

## Useful Checks

```bash
npm run dashboard:db:status
npm run dashboard:db:logs
npm run dashboard:db:stop
npm run check:dashboard
```

If you need the full setup walkthrough, see the backend README at [backend/README.md](backend/README.md) and the frontend README at [frontend/README.md](frontend/README.md).

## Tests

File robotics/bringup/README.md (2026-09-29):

# bringup

Top-level launch package for AMR-X. **Start here.**

Orchestrates the other packages into single commands.

## Contents

- `launch/simulation.launch.py` - the full digital twin: robot description +
  Gazebo + warehouse + spawn + ROS-Gazebo bridge + RViz, in one command.
- `launch/teleop.launch.py` - keyboard teleoperation.
- `launch/teleop_joy.launch.py` - gamepad teleoperation.
- `config/teleop_joy.yaml` - gamepad mapping.
- `rviz/simulation.rviz` - RViz layout (robot, LiDAR scan, odometry, TF).

## Run

```bash
ros2 launch bringup simulation.launch.py          # everything
ros2 launch bringup simulation.launch.py rviz:=false
ros2 launch bringup simulation.launch.py gui:=false
ros2 launch bringup simulation.launch.py simulator_variant:=fortress
```

This package has no predecessor in the original planning structure - it is the
new piece that ties the others together.

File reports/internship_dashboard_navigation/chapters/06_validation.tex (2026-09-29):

\chapter{Validation en simulation}
\label{chap:validation}

\section*{Introduction}
Ce chapitre présente la validation de la chaîne complète dans Gazebo. Il décrit
l'environnement et la méthode d'essai, puis les vérifications préalables et la
calibration des repères entre la carte Nav2 et le monde Gazebo. Il présente ensuite les
résultats mesurés et les points qui restent à valider. Toutes les valeurs données sont
issues de mesures réalisées en simulation.

\section{Environnement et méthode d'essai}
Les essais ont été réalisés sur un poste Ubuntu~24.04 avec ROS~2 Jazzy et Gazebo Harmonic,
dans le monde \code{warehouse\_harmonic}, avec la carte \code{warehouse\_harmonic.yaml}.
La chaîne complète était lancée par \code{scripts/run-all.sh}, fenêtre Gazebo ouverte
(figure~\ref{fig:gazebo}).

\begin{figure}[htbp]
\centering
\capture{gazebo_warehouse.png}{Fenêtre Gazebo : robot AMR-X dans l'entrepôt warehouse\_harmonic.}
\caption{Robot AMR-X simulé dans l'entrepôt Gazebo.}
\label{fig:gazebo}
\end{figure}

Pour obtenir des mesures reproductibles, les scénarios de navigation ont été pilotés par
un script de test qui appelle \emph{les mêmes services} que le dashboard,
\code{/dashboard/navigation/submit} et \code{/dashboard/navigation/cancel}, et enregistre
les changements de phase publiés par la passerelle. Les destinations libres et occupées
sont tirées de la costmap globale. La vérité terrain est la pose du modèle
\code{amr\_x} lue directement dans Gazebo (\code{gz model -m amr\_x -p}). L'erreur de
position affichée est définie par
\begin{equation}
  e = \sqrt{(x_{\text{passerelle}} - x_{\text{Gazebo}})^2 + (y_{\text{passerelle}} - y_{\text{Gazebo}})^2},
\end{equation}
où la pose de la passerelle est celle transmise au dashboard, dans le repère du monde.

\section{Vérifications préalables}
Avant les essais en simulation, la compilation et les tests automatisés ont été exécutés
sous Ubuntu (tableau~\ref{tab:prealables}).

\begin{table}[htbp]
\centering\small
\begin{tabular}{@{}ll@{}}
\toprule
\textbf{Vérification} & \textbf{Résultat} \\
\midrule
Compilation \code{colcon} des paquets \code{navigation} et \code{navigation\_msgs} & réussie \\
Génération de l'interface \code{SubmitNavigationGoal} & réussie \\
Tests unitaires Python des conversions & 5/5 réussis \\
Analyse statique du frontend (\code{oxlint}) & aucune erreur \\
Tests unitaires JavaScript & 5/5 réussis \\
Compilation de production du frontend (Vite) & réussie \\
Cohérence du manifeste des mondes SDF & à jour (6 mondes) \\
\bottomrule
\end{tabular}
\caption{Vérifications préalables sous Ubuntu.}
\label{tab:prealables}
\end{table}

\section{Calibration des repères carte / monde}

\subsection{Principe}
Le dashboard affiche le robot sur le plan du monde Gazebo, alors que Nav2 localise le robot
dans le repère \code{map} de sa carte. Pour que la position affichée soit exacte, la
passerelle doit connaître la pose de l'origine de \code{map} dans le monde
(chapitre~\ref{chap:conception}). Cette pose dépend de la façon dont la carte a été
enregistrée : une carte SLAM a pour origine la position du robot au début de
l'enregistrement. Elle doit donc être mesurée pour chaque carte.

\subsection{Mesure}
La mesure a été faite de deux façons indépendantes. D'abord, la position transmise au
dashboard sans calibration (décalages nuls) a été comparée à la position Gazebo en trois
endroits (tableau~\ref{tab:avant}). L'écart est pratiquement constant, d'environ 4,1~m,
et l'écart de cap reste inférieur à 0,6° : les deux repères sont simplement translatés
l'un par rapport à l'autre.

\begin{table}[htbp]
\centering\small
\begin{tabular}{@{}lccc@{}}
\toprule
\textbf{Position} & \textbf{Pose Gazebo (m)} & \textbf{Écart $e$ (m)} & \textbf{Écart de cap (°)} \\
\midrule
Position 1 & $(3{,}953 ; -1{,}450)$ & 4,094 & $-0{,}53$ \\
Position 2 & $(0{,}980 ; -2{,}931)$ & 4,108 & $0{,}40$ \\
Position 3 & $(-4{,}877 ; 1{,}458)$ & 4,131 & $-0{,}11$ \\
\bottomrule
\end{tabular}
\caption{Écart entre la position affichée et la position Gazebo, sans calibration.}
\label{tab:avant}
\end{table}

Ensuite, l'emprise de la carte \code{warehouse\_harmonic.yaml} a été comparée aux limites
du monde SDF. Le monde s'étend en $x$ de $-7{,}00$ à $6{,}31$~m et en $y$ de $-9{,}93$ à
$10{,}24$~m, alors que la zone connue de la carte s'étend en $x$ de $-5{,}73$ à $8{,}27$~m et
en $y$ de $-6{,}55$ à $14{,}30$~m. La carte est donc décalée d'environ $(+1{,}3 ; +3{,}9)$~m,
soit l'opposé de la position d'apparition du robot, $(-1{,}2639 ; -3{,}9049)$. Les deux
mesures concordent : l'origine du repère \code{map} est la position d'apparition du robot
dans le monde (figure~\ref{fig:reperes}).

\begin{figure}[htbp]
\centering
\begin{tikzpicture}[scale=0.48]
  \draw[gray!60,thin] (-7,-9.93) rectangle (6.31,10.24);
  \node[font=\scriptsize,gray,anchor=south west] at (-7,10.3) {limites du monde SDF};
  \draw[blue!60,thin,dashed] (-6.99,-10.45) rectangle (7.01,10.4);
  \node[font=\scriptsize,blue!70!black,anchor=north west] at (-6.99,-10.5) {emprise de la carte Nav2};
  \draw[fl,black] (0,0) -- (2.2,0) node[right,font=\scriptsize]{$x_w$};
  \draw[fl,black] (0,0) -- (0,2.2) node[above,font=\scriptsize]{$y_w$};
  \node[font=\scriptsize,anchor=south west] at (0.1,0.1) {$O_{\text{monde}}$};
  \draw[fl,blue!70!black] (-1.26,-3.9) -- (0.94,-3.9) node[right,font=\scriptsize]{$x_m$};
  \draw[fl,blue!70!black] (-1.26,-3.9) -- (-1.26,-1.7) node[above,font=\scriptsize]{$y_m$};
  \draw[red!70!black,thick,-{Stealth}] (0,0) -- (-1.2,-3.75);
  \node[font=\scriptsize,red!70!black,anchor=west] at (-0.35,-2.2) {$(t_x, t_y)$};
  \fill[red!70!black] (-1.26,-3.9) circle (4pt);
  \node[font=\scriptsize,align=center,anchor=north] at (-1.26,-4.3)
    {$O_{\text{map}}$ = apparition du robot\\$(-1{,}2639 ; -3{,}9049)$};
\end{tikzpicture}
\caption{Origine du repère \code{map} dans le monde Gazebo.}
\label{fig:reperes}
\end{figure}

\subsection{Paramètres retenus}
Les paramètres suivants sont appliqués au lancement par le script \code{run-all.sh} :
\begin{itemize}
  \item pose de l'origine de \code{map} dans le monde, transmise à la passerelle :
    $t_x = -1{,}2639$~m, $t_y = -3{,}9049$~m, $\theta = 0$ ;
  \item pose initiale transmise à AMCL : $(0 ; 0 ; 0)$ dans \code{map}, puisque le robot
    apparaît à l'origine de la carte.
\end{itemize}

\section{Résultats}

\subsection{Cohérence des positions}
Après calibration, l'écart entre la position transmise au dashboard et la position Gazebo
a été mesuré en trois endroits (tableau~\ref{tab:apres}). Il reste compris entre 0,6 et
5,6~cm, avec un écart de cap inférieur à 1°. La dernière mesure a été faite environ une
seconde après une annulation en cours de déplacement.

\begin{table}[htbp]
\centering\small
\begin{tabular}{@{}lccc@{}}
\toprule
\textbf{Position} & \textbf{Pose Gazebo (m)} & \textbf{Écart $e$ (m)} & \textbf{Écart de cap (°)} \\
\midrule
Position d'apparition & $(-1{,}264 ; -3{,}905)$ & 0,014 & $0{,}33$ \\
Après la navigation B & $(-3{,}246 ; -1{,}698)$ & 0,006 & $0{,}40$ \\
Après l'annulation F & $(-0{,}016 ; -6{,}077)$ & 0,056 & $-0{,}99$ \\
\bottomrule
\end{tabular}
\caption{Écart entre la position affichée et la position Gazebo, après calibration.}
\label{tab:apres}
\end{table}

\subsection{Résultats par scénario}
Le tableau~\ref{tab:resultats} présente les résultats des scénarios exécutés. Les lettres
reprennent la numérotation du protocole de validation du projet.

\begin{table}[htbp]
\centering\small
\begin{tabularx}{\linewidth}{@{}c>{\raggedright\arraybackslash}p{3.6cm}X@{}}
\toprule
\textbf{Réf.} & \textbf{Scénario} & \textbf{Résultat mesuré} \\
\midrule
A & Cohérence des positions & Écart de 0,6 à 5,6~cm et de moins de 1° en trois endroits (tableau~\ref{tab:apres}). \\
\addlinespace
B & Destination libre proche & But $(-3{,}30 ; -1{,}71)$, cap 90° : acquitté, phase \code{navigating} après 0,01~s, \code{succeeded} après 5,75~s. Erreur finale de position 5,6~cm ; cap final 101,0°. \\
\addlinespace
D & Destinations invalides & Cellule occupée et point hors carte : refusés (\og outside known free space or occupied \fg{}). Coordonnée non finie : refusée. Déplacement du robot pendant ces essais : 0,0~cm. \\
\addlinespace
F & Annulation en route & Robot en mouvement (4,1~m parcourus 6~s après l'envoi) ; annulation à 7,4~s : \code{canceling} puis \code{canceled} en 0,03~s. Déplacement dans les 3~s suivantes : 3,6~cm. \\
\addlinespace
G & Doublons et buts concurrents & Même \code{request\_id} renvoyé : refusé (\og already received \fg{}). Second but pendant la navigation : refusé (\og a goal is already active \fg{}). \\
\addlinespace
I & Simulation en pause & État publié à 3,6~Hz avant la pause, 0 message en 5~s pendant la pause, 3,8~Hz après la reprise, passerelle de nouveau prête. \\
\addlinespace
J & Mauvais monde & Demande avec \code{hospital-harmonic} : refusée (\og selected world does not match \fg{}). \\
\addlinespace
-- & Annulation sans but actif & Refusée (\og no active destination \fg{}). \\
\bottomrule
\end{tabularx}
\caption{Résultats mesurés par scénario, après calibration des repères.}
\label{tab:resultats}
\end{table}

\subsection{Illustration d'une navigation réussie}
La figure~\ref{fig:succes} montre une navigation capturée simultanément dans le dashboard
et dans Gazebo. Le robot, initialement en $(-0{,}05 ; -6{,}04)$, a reçu la destination
$(-0{,}55 ; -3{,}71)$ par le service de soumission. Nav2 a renvoyé un succès après
10,8~s ; dans Gazebo, le robot s'est arrêté à 0,9~cm de la destination, et la position
affichée dans le dashboard différait de 6,2~cm de la position Gazebo. Le dashboard montre
le déplacement du robot et la trace de son trajet, et le panneau de flotte indique le
résultat \code{succeeded} (figure~\ref{fig:statut}).

\begin{figure}[htbp]
\centering
\begin{subfigure}[b]{0.34\linewidth}\centering
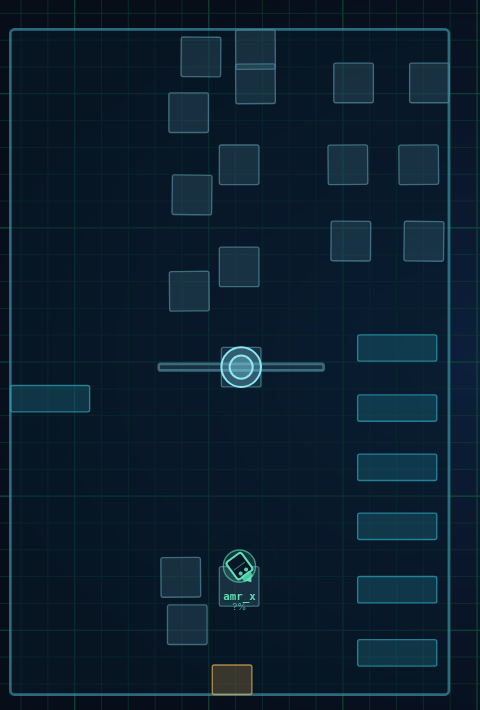
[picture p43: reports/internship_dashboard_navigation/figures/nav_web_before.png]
  
  \caption{Dashboard, avant.}
\end{subfigure}\hfill
\begin{subfigure}[b]{0.62\linewidth}\centering
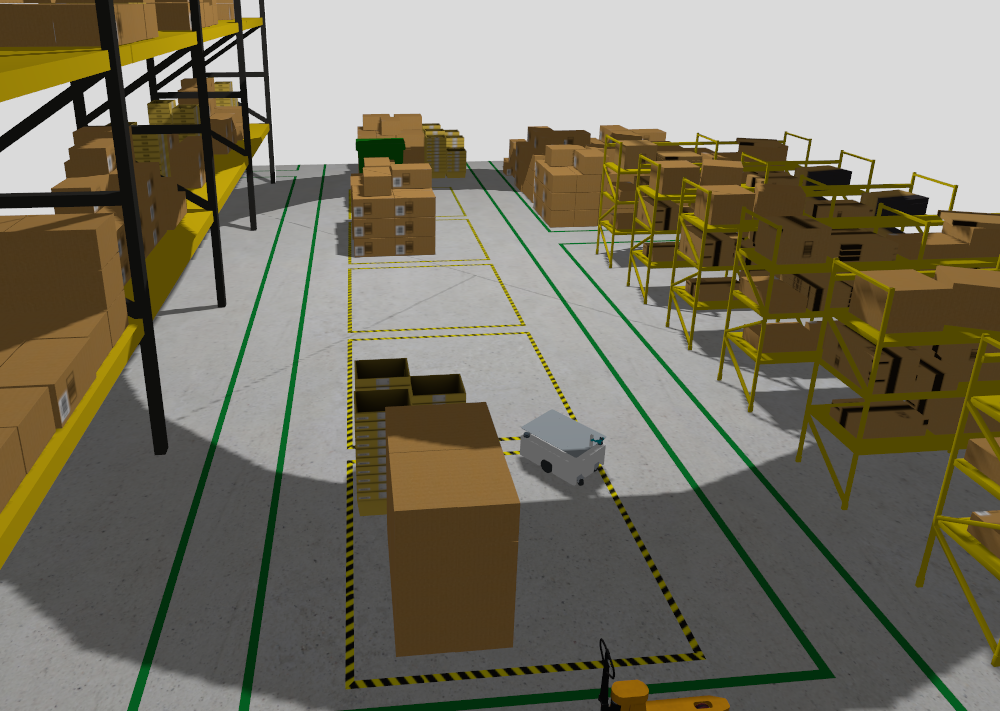
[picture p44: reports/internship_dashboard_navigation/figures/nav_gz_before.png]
  
  \caption{Gazebo, avant.}
\end{subfigure}\\[0.8em]
\begin{subfigure}[b]{0.34\linewidth}\centering
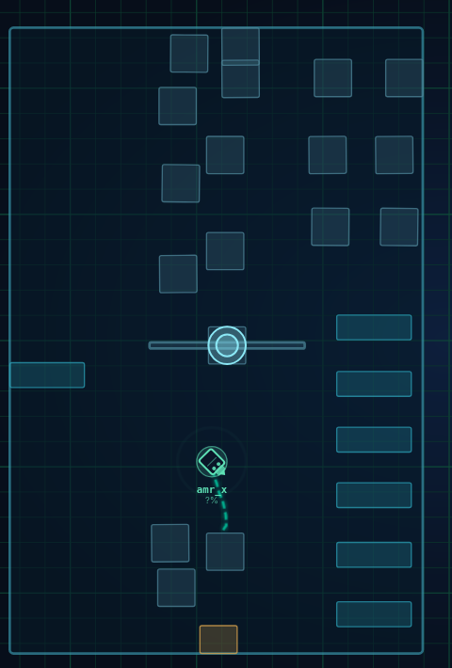
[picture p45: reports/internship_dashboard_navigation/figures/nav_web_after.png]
  
  \caption{Dashboard, après.}
\end{subfigure}\hfill
\begin{subfigure}[b]{0.62\linewidth}\centering
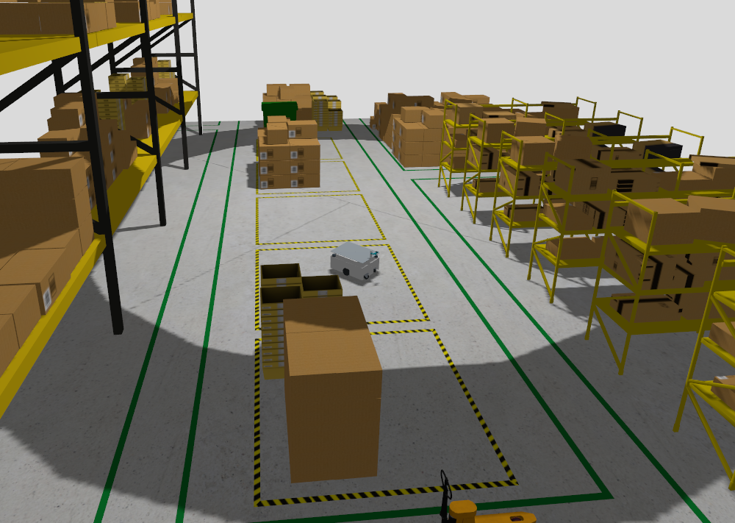
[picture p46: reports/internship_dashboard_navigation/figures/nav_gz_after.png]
  
  \caption{Gazebo, après.}
\end{subfigure}
\caption{Navigation réussie : déplacement du robot vu dans le dashboard et dans Gazebo.}
\label{fig:succes}
\end{figure}

\begin{figure}[htbp]
\centering

\caption{Résultat de la navigation affiché dans le panneau de flotte du dashboard.}
\label{fig:statut}
\end{figure}

\subsection{Analyse}
Les résultats montrent que la chaîne remplit les besoins fonctionnels : la destination
est acquittée immédiatement, la phase suit fidèlement l'exécution de Nav2 et la position
affichée correspond à celle du robot dans Gazebo à quelques centimètres près.

L'écart de cap final de 11° au scénario B reste inférieur à la tolérance angulaire
configurée dans Nav2 (\code{yaw\_goal\_tolerance} de 0,25~rad, soit 14,3°) ; de même,
l'erreur de position de 5,6~cm est inférieure à la tolérance de 0,25~m. Nav2 considère le
but atteint dès que ces tolérances sont respectées ; une précision plus fine relèverait du
réglage de Nav2 et non du dashboard.

La fréquence de l'état observée en temps réel (3,6 à 3,8~Hz) est légèrement inférieure aux
4~Hz nominaux. Le temporisateur de la passerelle étant cadencé sur le temps simulé, cette
fréquence suit la vitesse d'exécution de la simulation ; c'est aussi ce qui provoque l'arrêt
de la publication lorsque Gazebo est en pause, et donc le blocage des commandes dans le
dashboard après 2,5~s.

La latence d'acquittement mesurée (2~ms) a été obtenue par un client ROS local ; elle
n'inclut pas le passage par rosbridge et le navigateur.

\section{Points restant à valider}
Certains scénarios du protocole n'ont pas encore été exécutés dans la simulation :
\begin{itemize}
  \item \textbf{C} -- détour autour d'un obstacle : non mesuré spécifiquement ;
  \item \textbf{E} -- destination libre mais inaccessible : à réaliser pour vérifier que
    l'échec de Nav2 est bien affiché ;
  \item \textbf{H} -- coupure de rosbridge, puis reconnexion sans renvoi automatique ;
  \item \textbf{K} et \textbf{L} -- mode démonstration et changement d'adresse dans
    \emph{Settings}, vérifiés jusqu'ici par le test navigateur avec un faux serveur ROS
    uniquement ;
  \item cellule \emph{inconnue} : la costmap globale utilisée ne contenait aucune cellule
    inconnue ; ce cas n'est couvert que par les tests unitaires.
\end{itemize}
Ces essais doivent être conduits depuis l'interface web, en notant pour chacun la
configuration, le but, le résultat, la durée et les observations.

\section{Limites}
La solution est conçue pour la simulation. Elle ne gère qu'un robot et un monde à la
fois, n'arbitre pas les commandes venant d'autres sources (RViz, téléopération) et
n'ajoute pas d'authentification au niveau de rosbridge : elle n'est pas destinée à être
exposée sur un réseau ouvert. Fermer la page ou perdre la connexion n'arrête pas la
navigation en cours. Enfin, l'identifiant du monde et les décalages de repère sont
configurés par l'opérateur au lancement ; ils ne prouvent pas à eux seuls que le bon monde
et la bonne carte sont chargés, d'où l'intérêt de la vérification de position décrite
ci-dessus.

\section*{Conclusion}
Les essais en simulation ont permis de valider l'envoi de destinations, le suivi de
l'état, l'annulation, le refus des demandes invalides et la cohérence de la position
affichée, à quelques centimètres près après calibration des repères entre la carte Nav2 et
le monde Gazebo.

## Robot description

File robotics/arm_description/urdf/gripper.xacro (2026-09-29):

<?xml version="1.0"?>
<robot xmlns:xacro="http://www.ros.org/wiki/xacro">

  <xacro:property name="joint_effort" value="56.0"/>
  <xacro:property name="joint_velocity" value="2.792527"/>
  <xacro:property name="joint_damping" value="0.0"/>
  <xacro:property name="joint_friction" value="0.0"/>

  <xacro:property name="gripper_link_mass" value="0.007"/>
  <xacro:property name="gripper_link_ixx" value="1e-6"/>
  <xacro:property name="gripper_link_iyy" value="1e-6"/>
  <xacro:property name="gripper_link_izz" value="1e-6"/>

  <xacro:macro name="gripper_link_inertial">
    <inertial>
      <origin xyz="0 0 0.0" rpy="0 0 0"/>
      <mass value="${gripper_link_mass}"/>
      <inertia ixx="${gripper_link_ixx}" ixy="0.0" ixz="0.0" iyy="${gripper_link_iyy}" iyz="0.0" izz="${gripper_link_izz}"/>
    </inertial>
  </xacro:macro>

  <xacro:macro name="gripper" params="parent prefix *origin">

    <link name="${prefix}gripper_base">
      <inertial>
        <origin xyz="0 0 0.0" rpy="0 0 0"/>
        <mass value="0.07"/>
        <inertia ixx="0.000010725" ixy="0.0" ixz="0.0" iyy="0.000014392" iyz="0.0" izz="0.000018517"/>
      </inertial>
      <visual>
        <geometry>
          <mesh filename="file://$(find arm_description)/meshes/adaptive_gripper/visual/gripper_base.dae"/>
        </geometry>
        <origin xyz="0.0 0.0 -0.012" rpy="0 0 0"/>
      </visual>
      <collision>
        <geometry>
          <box size="0.065 0.025 0.025"/>
        </geometry>
        <origin xyz="0.0 0.0 0.0" rpy="0 0 0"/>
      </collision>
    </link>

    <joint name="${prefix}${parent}_to_${prefix}gripper_base" type="fixed">
      <parent link="${prefix}${parent}"/>
      <child link="${prefix}gripper_base"/>
      <xacro:insert_block name="origin"/>
    </joint>

    <link name="${prefix}gripper_left1">
      <xacro:gripper_link_inertial/>
      <visual>
        <geometry>
          <mesh filename="file://$(find arm_description)/meshes/adaptive_gripper/visual/gripper_left1.dae"/>
        </geometry>
        <origin xyz="0.039 -0.0133 -0.012" rpy="0 0 0"/>
      </visual>
      <collision>
        <geometry>
          <box size="0.013 0.02 0.015"/>
        </geometry>
        <origin xyz="0.013 0.042 -0.010" rpy="0 0 0"/>
      </collision>
    </link>

    <link name="${prefix}gripper_left2">
      <xacro:gripper_link_inertial/>
      <visual>
        <geometry>
          <mesh filename="file://$(find arm_description)/meshes/adaptive_gripper/visual/gripper_left2.dae"/>
        </geometry>
        <origin xyz="0.005 -0.0195 -0.012" rpy="0 0 0"/>
      </visual>
      <collision>
        <geometry>
          <box size="0.02 0.02 0.02"/>
        </geometry>
        <origin xyz="-0.025 0.0 -0.010" rpy="0 0 0"/>
      </collision>
    </link>

    <link name="${prefix}gripper_left3">
      <xacro:gripper_link_inertial/>
      <visual>
        <geometry>
          <mesh filename="file://$(find arm_description)/meshes/adaptive_gripper/visual/gripper_left3.dae"/>
        </geometry>
        <origin xyz="0.012 0.0025 -0.012" rpy="0 0 0"/>
      </visual>
      <collision>
        <geometry>
          <box size="0.01 0.01 0.01"/>
        </geometry>
        <origin xyz="-0.014 0.005 0.005" rpy="0 0 0"/>
      </collision>
    </link>

    <link name="${prefix}gripper_right1">
      <xacro:gripper_link_inertial/>
      <visual>
        <geometry>
          <mesh filename="file://$(find arm_description)/meshes/adaptive_gripper/visual/gripper_right1.dae"/>
        </geometry>
        <origin xyz="-0.039 -0.0133 -0.012" rpy="0 0 0"/>
      </visual>
      <collision>
        <geometry>
          <box size="0.013 0.02 0.015"/>
        </geometry>
        <origin xyz="-0.013 0.042 -0.010" rpy="0 0 0"/>
      </collision>
    </link>

    <link name="${prefix}gripper_right2">
      <xacro:gripper_link_inertial/>
      <visual>
        <geometry>
          <mesh filename="file://$(find arm_description)/meshes/adaptive_gripper/visual/gripper_right2.dae"/>
        </geometry>
        <origin xyz="-0.005 -0.0195 -0.012" rpy="0 0 0"/>
      </visual>
      <collision>
        <geometry>
          <box size="0.02 0.02 0.02"/>
        </geometry>
        <origin xyz="0.025 0.0 -0.010" rpy="0 0 0"/>
      </collision>
    </link>

    <link name="${prefix}gripper_right3">
      <xacro:gripper_link_inertial/>
      <visual>
        <geometry>
          <mesh filename="file://$(find arm_description)/meshes/adaptive_gripper/visual/gripper_right3.dae"/>
        </geometry>
        <origin xyz="-0.012 0.0025 -0.012" rpy="0 0 0"/>
      </visual>
      <collision>
        <geometry>
          <box size="0.01 0.01 0.01"/>
        </geometry>
        <origin xyz="0.014 0.005 0.005" rpy="0 0 0"/>
      </collision>
    </link>

    <joint name="${prefix}gripper_controller" type="revolute">
      <axis xyz="0 0 1"/>
      <limit effort="${joint_effort}" lower="-0.7" upper="0.15" velocity="${joint_velocity}"/>
      <parent link="${prefix}gripper_base"/>
      <child link="${prefix}gripper_left3"/>
      <origin xyz="-0.012 0.005 0" rpy="0 0 0"/>
      <dynamics damping="${joint_damping}" friction="${joint_friction}"/>
    </joint>

    <joint name="${prefix}gripper_base_to_${prefix}gripper_left2" type="revolute">
      <axis xyz="0 0 1"/>
      <limit effort="${joint_effort}" lower="-0.8" upper="0.5" velocity="${joint_velocity}"/>
      <parent link="${prefix}gripper_base"/>
      <child link="${prefix}gripper_left2"/>
      <origin xyz="-0.005 0.027 0" rpy="0 0 0"/>
      <mimic joint="${prefix}gripper_controller" multiplier="1.0" offset="0"/>
      <dynamics damping="${joint_damping}" friction="${joint_friction}"/>
    </joint>

    <joint name="${prefix}gripper_left3_to_${prefix}gripper_left1" type="revolute">
      <axis xyz="0 0 1"/>
      <limit effort="${joint_effort}" lower="-0.5" upper="0.5" velocity="${joint_velocity}"/>
      <parent link="${prefix}gripper_left3"/>
      <child link="${prefix}gripper_left1"/>
      <origin xyz="-0.027 0.016 0" rpy="0 0 0"/>
      <mimic joint="${prefix}gripper_controller" multiplier="-1.0" offset="0"/>
      <dynamics damping="${joint_damping}" friction="${joint_friction}"/>
    </joint>

    <joint name="${prefix}gripper_base_to_${prefix}gripper_right3" type="revolute">
      <axis xyz="0 0 1"/>
      <limit effort="${joint_effort}" lower="-0.15" upper="0.7" velocity="${joint_velocity}"/>
      <parent link="${prefix}gripper_base"/>
      <child link="${prefix}gripper_right3"/>
      <origin xyz="0.012 0.005 0" rpy="0 0 0"/>
      <mimic joint="${prefix}gripper_controller" multiplier="-1.0" offset="0"/>
      <dynamics damping="${joint_damping}" friction="${joint_friction}"/>
    </joint>

    <joint name="${prefix}gripper_base_to_${prefix}gripper_right2" type="revolute">
      <axis xyz="0 0 1"/>
      <limit effort="${joint_effort}" lower="-0.5" upper="0.8" velocity="${joint_velocity}"/>
      <parent link="${prefix}gripper_base"/>
      <child link="${prefix}gripper_right2"/>
      <origin xyz="0.005 0.027 0" rpy="0 0 0"/>
      <mimic joint="${prefix}gripper_controller" multiplier="-1.0" offset="0"/>
      <dynamics damping="${joint_damping}" friction="${joint_friction}"/>
    </joint>

    <joint name="${prefix}gripper_right3_to_${prefix}gripper_right1" type="revolute">
      <axis xyz="0 0 1"/>
      <limit effort="${joint_effort}" lower="-0.5" upper="0.5" velocity="${joint_velocity}"/>
      <parent link="${prefix}gripper_right3"/>
      <child link="${prefix}gripper_right1"/>
      <origin xyz="0.027 0.016 0" rpy="0 0 0"/>
      <mimic joint="${prefix}gripper_controller" multiplier="1.0" offset="0"/>
      <dynamics damping="${joint_damping}" friction="${joint_friction}"/>
    </joint>

    <gazebo reference="${prefix}gripper_base">
      <visual>
        <material>
          <ambient>1 1 1 1</ambient>
          <diffuse>1 1 1 1</diffuse>
          <specular>1 1 1 1</specular>
        </material>
      </visual>
    </gazebo>
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

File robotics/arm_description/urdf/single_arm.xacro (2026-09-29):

<?xml version="1.0"?>
<robot xmlns:xacro="http://www.ros.org/wiki/xacro">
  <xacro:property name="joint_effort" value="56.0"/>
  <xacro:property name="joint_velocity" value="2.792527"/>
  <xacro:property name="joint_damping" value="0.0"/>
  <xacro:property name="joint_friction" value="0.0"/>
  <xacro:property name="link1_mass" value="0.12"/>
  <xacro:property name="link2_mass" value="0.19"/>
  <xacro:property name="link3_mass" value="0.16"/>
  <xacro:property name="link4_mass" value="0.124"/>
  <xacro:property name="link5_mass" value="0.11"/>
  <xacro:property name="link6_mass" value="0.0739"/>
  <xacro:property name="flange_mass" value="0.035"/>
  <xacro:macro name="link_inertial" params="mass ixx iyy izz">
    <inertial>
      <origin xyz="0 0 0.0" rpy="0 0 0"/>
      <mass value="${mass}"/>
      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
    </inertial>
  </xacro:macro>
  <xacro:macro name="material_visual" params="ref_link ambient diffuse specular">
    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
  </xacro:macro>

  <xacro:macro name="g_shape_base" params="base_link prefix">
    <link name="${prefix}${base_link}">
      <inertial>
        <origin xyz="0 0 0.0" rpy="0 0 0"/>
        <mass value="0.33"/>
        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
      </inertial>
      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
    </link>

    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
  </xacro:macro>



  <xacro:macro name="single_arm" params="base_link flange_link prefix *origin">
    <link name="${prefix}link1">
      <xacro:link_inertial mass="${link1_mass}" ixx="0.000148" iyy="0.000148" izz="0.000096"/>
      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
    </link>
    <link name="${prefix}link2">
      <xacro:link_inertial mass="${link2_mass}" ixx="0.000148" iyy="0.000148" izz="0.000096"/>
      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
    </link>
    <link name="${prefix}link3">
      <xacro:link_inertial mass="${link3_mass}" ixx="0.000148" iyy="0.000148" izz="0.000096"/>
      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
    </link>
    <link name="${prefix}link4">
      <xacro:link_inertial mass="${link4_mass}" ixx="0.000103" iyy="0.000103" izz="0.000096"/>
      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
    </link>
    <link name="${prefix}link5">
      <xacro:link_inertial mass="${link5_mass}" ixx="0.000103" iyy="0.000103" izz="0.000096"/>
      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
    </link>
    <link name="${prefix}link6">
      <xacro:link_inertial mass="${link6_mass}" ixx="0.00006649" iyy="0.00006649" izz="0.000096"/>
      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
    </link>
    <link name="${prefix}${flange_link}">
      <xacro:link_inertial mass="${flange_mass}" ixx="0.0000149" iyy="0.0000149" izz="0.0000196"/>
      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
    </link>
    <joint name="${prefix}${base_link}_to_${prefix}link1" type="fixed">
      <parent link="${prefix}${base_link}"/>
      <child link="${prefix}link1"/>
      <xacro:insert_block name="origin"/>
    </joint>
    <joint name="${prefix}link1_to_${prefix}link2" type="revolute">
      <axis xyz="0 0 1"/>
      <limit effort="${joint_effort}" lower="-2.879793" upper="2.879793" velocity="${joint_velocity}"/>
      <parent link="${prefix}link1"/>
      <child link="${prefix}link2"/>
      <origin xyz="0 0 0.13156" rpy="0 0 ${pi/2}"/>
      <dynamics damping="${joint_damping}" friction="${joint_friction}"/>
    </joint>
    <joint name="${prefix}link2_to_${prefix}link3" type="revolute">
      <axis xyz="0 0 1"/>
      <limit effort="${joint_effort}" lower="-2.879793" upper="2.879793" velocity="${joint_velocity}"/>
      <parent link="${prefix}link2"/>
      <child link="${prefix}link3"/>
      <origin xyz="0 0 -0.001" rpy="0 ${pi/2} ${-pi/2}"/>
      <dynamics damping="${joint_damping}" friction="${joint_friction}"/>
    </joint>
    <joint name="${prefix}link3_to_${prefix}link4" type="revolute">
      <axis xyz="0 0 1"/>
      <limit effort="${joint_effort}" lower="-2.879793" upper="2.879793" velocity="${joint_velocity}"/>
      <parent link="${prefix}link3"/>
      <child link="${prefix}link4"/>
      <origin xyz="-0.1104 0 0" rpy="0 0 0"/>
      <dynamics damping="${joint_damping}" friction="${joint_friction}"/>
    </joint>
    <joint name="${prefix}link4_to_${prefix}link5" type="revolute">
      <axis xyz="0 0 1"/>
      <limit effort="${joint_effort}" lower="-2.879793" upper="2.879793" velocity="${joint_velocity}"/>
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

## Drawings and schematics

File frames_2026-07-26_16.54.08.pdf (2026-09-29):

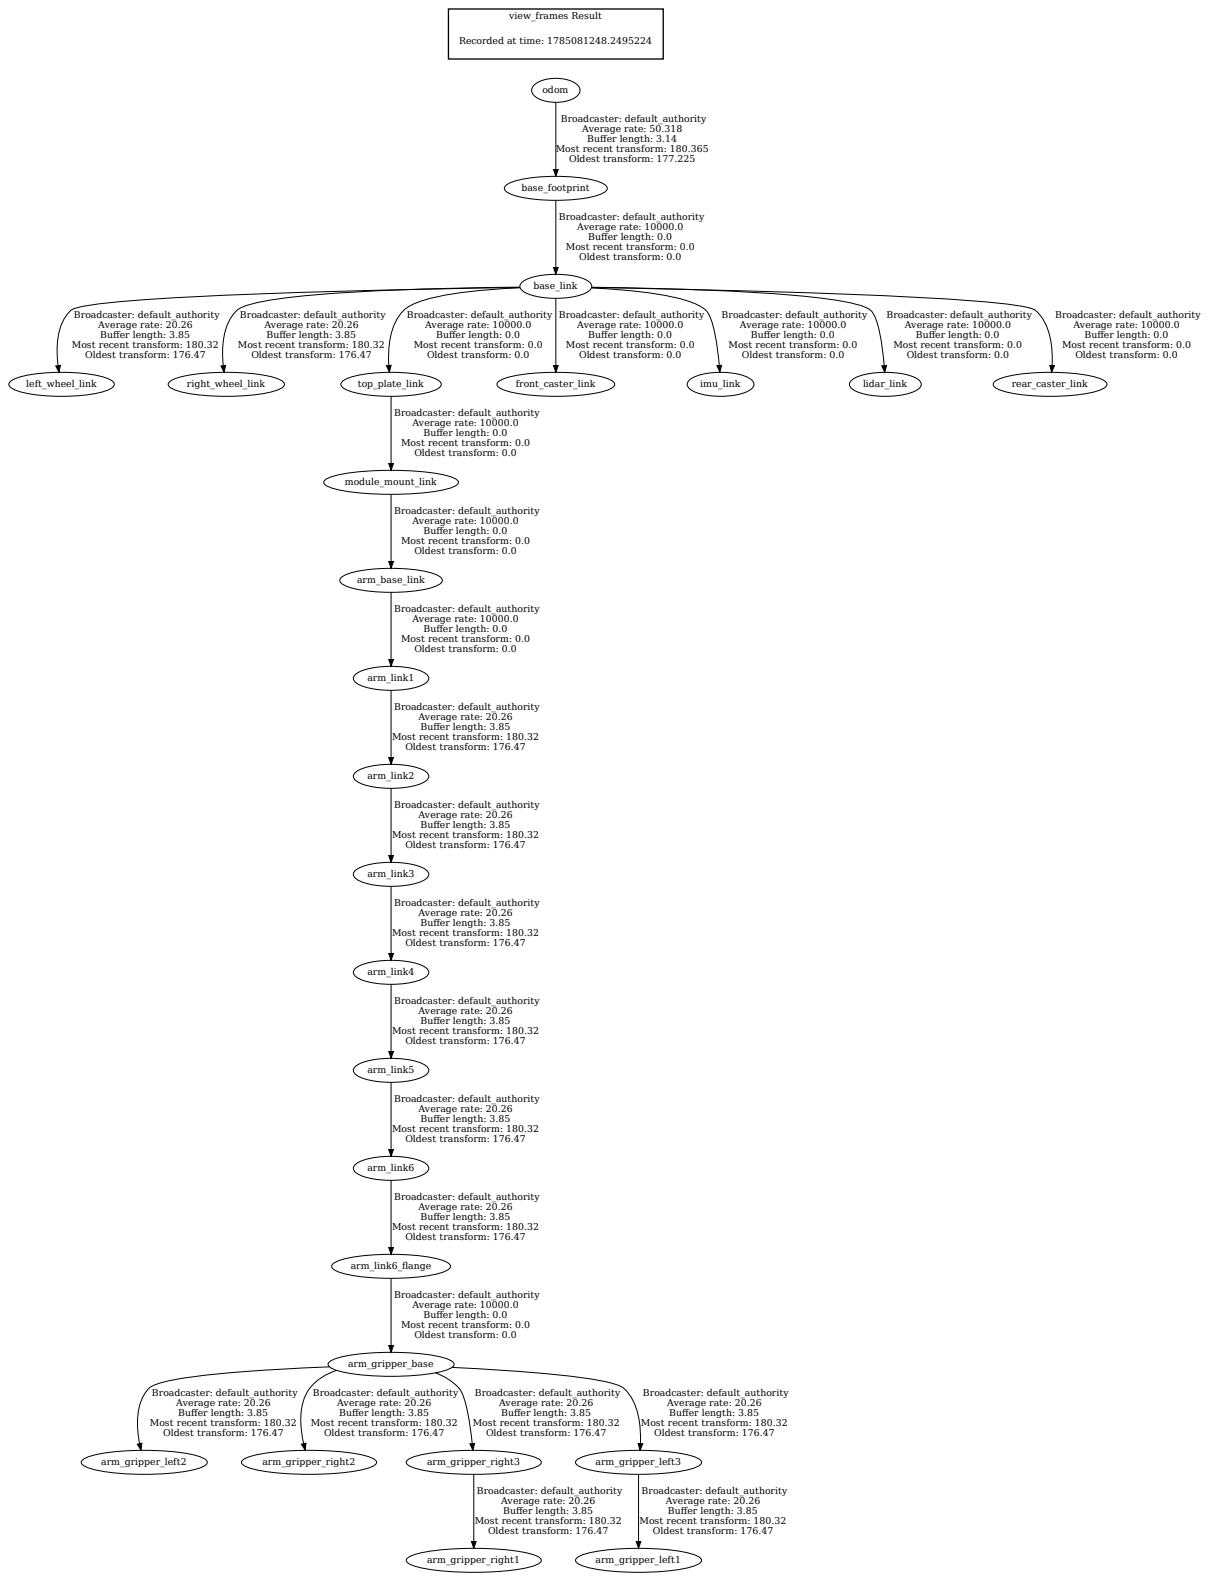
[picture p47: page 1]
view_frames Result; arm_gripper_base; arm_gripper_left2; arm_gripper_right2; arm_gripper_right3; arm_gripper_left3; arm_link6_flange; arm_gripper_right1; arm_gripper_left1; arm_link1; arm_link2; arm_link3; arm_base_link; arm_link4; arm_link5; arm_link6; base_link; left_wheel_link; right_wheel_link; top_plate_link; front_caster_link; imu_link; lidar_link; rear_caster_link; base_footprint; module_mount_link; odom

Recorded at time: 1785081248.2495224

Broadcaster: default_authority
Average rate: 50.318
Buffer length: 3.14
Most recent transform: 180.365
Oldest transform: 177.225

Average rate: 10000.0
Buffer length: 0.0
Most recent transform: 0.0
Oldest transform: 0.0

Average rate: 20.26
Buffer length: 3.85
Most recent transform: 180.32
Oldest transform: 176.47

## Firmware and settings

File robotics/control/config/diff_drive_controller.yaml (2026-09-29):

# =============================================================================
# AMR-X  -  ros2_control / diff_drive_controller configuration
# =============================================================================
# This is the ALTERNATIVE control path. The default simulation uses the Gazebo
# DiffDrive *system plugin* (simplest, most stable for demos). If you instead
# want the full ros2_control framework (closer to the real robot, where a real
# hardware interface replaces the simulated one), use this config together with
# ign_ros2_control / gz_ros2_control and the <ros2_control> URDF block.
#
# Values mirror config/robot_params.yaml and project_specs.json.
# =============================================================================
controller_manager:
  ros__parameters:
    update_rate: 50          # Hz, matches encoder publish rate

    joint_state_broadcaster:
      type: joint_state_broadcaster/JointStateBroadcaster

    diff_drive_controller:
      type: diff_drive_controller/DiffDriveController

# -----------------------------------------------------------------------------
diff_drive_controller:
  ros__parameters:
    left_wheel_names: ["left_wheel_joint"]
    right_wheel_names: ["right_wheel_joint"]

    wheel_separation: 0.420       # m  (robot_params.yaml wheel.separation)
    wheel_radius: 0.0825          # m  (robot_params.yaml wheel.radius)

    wheel_separation_multiplier: 1.0
    left_wheel_radius_multiplier: 1.0
    right_wheel_radius_multiplier: 1.0

    # Odometry
    publish_rate: 50.0
    odom_frame_id: odom
    base_frame_id: base_footprint
    enable_odom_tf: true
    open_loop: false
    position_feedback: true

    # Command interface
    use_stamped_vel: false

    # Limits (from project_specs.json operating speeds + design accel)
    linear.x.has_velocity_limits: true
    linear.x.max_velocity: 1.5        # operating_speed_max_mps
    linear.x.min_velocity: -1.5
    linear.x.has_acceleration_limits: true
    linear.x.max_acceleration: 1.0
    linear.x.min_acceleration: -1.0

    angular.z.has_velocity_limits: true
    angular.z.max_velocity: 1.5
    angular.z.min_velocity: -1.5
    angular.z.has_acceleration_limits: true
    angular.z.max_acceleration: 2.0
    angular.z.min_acceleration: -2.0

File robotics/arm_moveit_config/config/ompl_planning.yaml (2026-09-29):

planning_plugins:
  - ompl_interface/OMPLPlanner
# To optionally use Ruckig for jerk-limited smoothing, add this line to the request adapters below
# default_planner_request_adapters/AddRuckigTrajectorySmoothing
request_adapters:
  - default_planning_request_adapters/ResolveConstraintFrames
  - default_planning_request_adapters/ValidateWorkspaceBounds
  - default_planning_request_adapters/CheckStartStateBounds
  - default_planning_request_adapters/CheckStartStateCollision
response_adapters:
  - default_planning_response_adapters/AddTimeOptimalParameterization
  - default_planning_response_adapters/ValidateSolution
  - default_planning_response_adapters/DisplayMotionPath
planner_configs:
  APSConfigDefault:
    type: geometric::AnytimePathShortening
    shortcut: 1  # Attempt to shortcut all new solution paths
    hybridize: 1  # Compute hybrid solution trajectories
    max_hybrid_paths: 36  # Number of hybrid paths generated per iteration
    num_planners: 8  # The number of default planners to use for planning
    planners: "RRTConnect,RRTConnect,RRTConnect,RRTConnect,RRTConnect,RRTConnect,RRTConnect,RRTConnect"  # A comma-separated list of planner types (e.g., "PRM,EST,RRTConnect"Optionally, planner parameters can be passed to change the default:"PRM[max_nearest_neighbors=5],EST[goal_bias=.5],RRT[range=10. goal_bias=.1]"
  SBLkConfigDefault:
    type: geometric::SBL
    range: 0.0  # Max motion added to tree. ==> maxDistance_ default: 0.0, if 0.0, set on setup()
  ESTkConfigDefault:
    type: geometric::EST
    range: 0.0  # Max motion added to tree. ==> maxDistance_ default: 0.0, if 0.0 setup()
    goal_bias: 0.05  # When close to goal select goal, with this probability. default: 0.05
  LBKPIECEkConfigDefault:
    type: geometric::LBKPIECE
    range: 0.0  # Max motion added to tree. ==> maxDistance_ default: 0.0, if 0.0, set on setup()
    border_fraction: 0.9  # Fraction of time focused on boarder default: 0.9
    min_valid_path_fraction: 0.5  # Accept partially valid moves above fraction. default: 0.5
  BKPIECEkConfigDefault:
    type: geometric::BKPIECE
    range: 0.0  # Max motion added to tree. ==> maxDistance_ default: 0.0, if 0.0, set on setup()
    border_fraction: 0.9  # Fraction of time focused on boarder default: 0.9
    failed_expansion_score_factor: 0.5  # When extending motion fails, scale score by factor. default: 0.5
    min_valid_path_fraction: 0.5  # Accept partially valid moves above fraction. default: 0.5
  KPIECEkConfigDefault:
    type: geometric::KPIECE
    range: 0.0  # Max motion added to tree. ==> maxDistance_ default: 0.0, if 0.0, set on setup()
    goal_bias: 0.05  # When close to goal select goal, with this probability. default: 0.05
    border_fraction: 0.9  # Fraction of time focused on boarder default: 0.9 (0.0,1.]
    failed_expansion_score_factor: 0.5  # When extending motion fails, scale score by factor. default: 0.5
    min_valid_path_fraction: 0.5  # Accept partially valid moves above fraction. default: 0.5
  RRTkConfigDefault:
    type: geometric::RRT
    range: 0.0  # Max motion added to tree. ==> maxDistance_ default: 0.0, if 0.0, set on setup()
    goal_bias: 0.05  # When close to goal select goal, with this probability? default: 0.05
  RRTConnectkConfigDefault:
    type: geometric::RRTConnect
    range: 0.0  # Max motion added to tree. ==> maxDistance_ default: 0.0, if 0.0, set on setup()
  RRTstarkConfigDefault:
    type: geometric::RRTstar
    range: 0.0  # Max motion added to tree. ==> maxDistance_ default: 0.0, if 0.0, set on setup()
    goal_bias: 0.05  # When close to goal select goal, with this probability? default: 0.05
    delay_collision_checking: 1  # Stop collision checking as soon as C-free parent found. default 1
  TRRTkConfigDefault:
    type: geometric::TRRT
    range: 0.0  # Max motion added to tree. ==> maxDistance_ default: 0.0, if 0.0, set on setup()
    goal_bias: 0.05  # When close to goal select goal, with this probability? default: 0.05
    max_states_failed: 10  # when to start increasing temp. default: 10
    temp_change_factor: 2.0  # how much to increase or decrease temp. default: 2.0
    min_temperature: 10e-10  # lower limit of temp change. default: 10e-10
    init_temperature: 10e-6  # initial temperature. default: 10e-6
    frountier_threshold: 0.0  # dist new state to nearest neighbor to disqualify as frontier. default: 0.0 set in setup()
    frountierNodeRatio: 0.1  # 1/10, or 1 nonfrontier for every 10 frontier. default: 0.1
    k_constant: 0.0  # value used to normalize expresssion. default: 0.0 set in setup()
  PRMkConfigDefault:
    type: geometric::PRM
    max_nearest_neighbors: 10  # use k nearest neighbors. default: 10
  PRMstarkConfigDefault:
    type: geometric::PRMstar
  FMTkConfigDefault:
    type: geometric::FMT
    num_samples: 1000  # number of states that the planner should sample. default: 1000
    radius_multiplier: 1.1  # multiplier used for the nearest neighbors search radius. default: 1.1
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

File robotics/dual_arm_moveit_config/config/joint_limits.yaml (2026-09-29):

joint_limits:

  # ============================================================
  # LEFT ARM
  # Values matched to the URDF
  # ============================================================

  shoulder1_joint:
    has_velocity_limits: true
    max_velocity: 1.0
    has_acceleration_limits: true
    max_acceleration: 5.0
    has_deceleration_limits: true
    max_deceleration: 5.0
    has_jerk_limits: false
    max_effort: 300.0

  shoulder2_joint:
    has_velocity_limits: true
    max_velocity: 1.0
    has_acceleration_limits: true
    max_acceleration: 5.0
    has_deceleration_limits: true
    max_deceleration: 5.0
    has_jerk_limits: false
    max_effort: 300.0

  shoulder3_joint:
    has_velocity_limits: true
    max_velocity: 1.0
    has_acceleration_limits: true
    max_acceleration: 5.0
    has_deceleration_limits: true
    max_deceleration: 5.0
    has_jerk_limits: false
    max_effort: 250.0

  shoulder4_joint:
    has_velocity_limits: true
    max_velocity: 1.0
    has_acceleration_limits: true
    max_acceleration: 5.0
    has_deceleration_limits: true
    max_deceleration: 5.0
    has_jerk_limits: false
    max_effort: 200.0

  shoulder5_joint:
    has_velocity_limits: true
    max_velocity: 1.0
    has_acceleration_limits: true
    max_acceleration: 5.0
    has_deceleration_limits: true
    max_deceleration: 5.0
    has_jerk_limits: false
    max_effort: 150.0

  shoulder6_joint:
    has_velocity_limits: true
    max_velocity: 1.0
    has_acceleration_limits: true
    max_acceleration: 5.0
    has_deceleration_limits: true
    max_deceleration: 5.0
    has_jerk_limits: false
    max_effort: 150.0

  wrist_joint:
    has_velocity_limits: true
    max_velocity: 1.0
    has_acceleration_limits: true
    max_acceleration: 5.0
    has_deceleration_limits: true
    max_deceleration: 5.0
    has_jerk_limits: false
    max_effort: 100.0


  # ============================================================
  # RIGHT ARM
  # Values matched to the URDF
  # ============================================================

  shoulderR_joint:
    has_velocity_limits: true
    max_velocity: 1.0
    has_acceleration_limits: true
    max_acceleration: 5.0
    has_deceleration_limits: true
    max_deceleration: 5.0
    has_jerk_limits: false
    max_effort: 300.0

  shoulderR_2_joint:
    has_velocity_limits: true
    max_velocity: 1.0
    has_acceleration_limits: true
    max_acceleration: 5.0
    has_deceleration_limits: true
    max_deceleration: 5.0
    has_jerk_limits: false
    max_effort: 300.0

  shoulderR_3joint:
    has_velocity_limits: true
    max_velocity: 1.0
    has_acceleration_limits: true
    max_acceleration: 5.0
    has_deceleration_limits: true
    max_deceleration: 5.0
    has_jerk_limits: false
    max_effort: 250.0

  shoulderR_4joint:
    has_velocity_limits: true
    max_velocity: 1.0
    has_acceleration_limits: true
    max_acceleration: 5.0
    has_deceleration_limits: true
    max_deceleration: 5.0
    has_jerk_limits: false
    max_effort: 200.0

  shoulderR_5joint:
    has_velocity_limits: true
    max_velocity: 1.0
    has_acceleration_limits: true
    max_acceleration: 5.0
    has_deceleration_limits: true
    max_deceleration: 5.0
    has_jerk_limits: false
    max_effort: 150.0

  shoulderR_6joint:
    has_velocity_limits: true
    max_velocity: 1.0
    has_acceleration_limits: true
    max_acceleration: 5.0
    has_deceleration_limits: true
    max_deceleration: 5.0
    has_jerk_limits: false
    max_effort: 150.0

  wristR_joint:
    has_velocity_limits: true
    max_velocity: 1.0
    has_acceleration_limits: true
    max_acceleration: 5.0
    has_deceleration_limits: true
    max_deceleration: 5.0
    has_jerk_limits: false
    max_effort: 100.0

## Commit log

2026-09-29 Import AMR-X with ROS dashboard navigation and Ubuntu handoff
    [3 Finger Gripper Final Assembly.SLDASM, ABB_ROBOTIC_ARM - Copy.SLDASM, ABB_ROBOTIC_ARM.SLDASM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]
2026-09-29 Rewrite internship report for Linda Ouaghlani and add narrated video
    - Report now presents CyberMech Systems, the modular autonomous robot
    AMR-X and its autonomous environment, then the intern's work, design,
    implementation and validation; the problems section is removed and
    the map/world offset is presented as a calibration step.
    - Cover page and acknowledgements use the internship certificate
    details (1 July - 31 August 2026); INSAT supervisor removed.
    - Add video/make_video.py and the generated 3-minute presentation video
    with French narration (Piper TTS) for non-specialist viewers.
